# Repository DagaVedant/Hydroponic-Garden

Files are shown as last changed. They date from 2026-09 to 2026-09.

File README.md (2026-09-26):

# Vertical Hydroponic Garden
a fully MODULAR, 3D PRINTED hydroponic tower which needs NO EXTRA tubing because its designed to distribute the water evenly


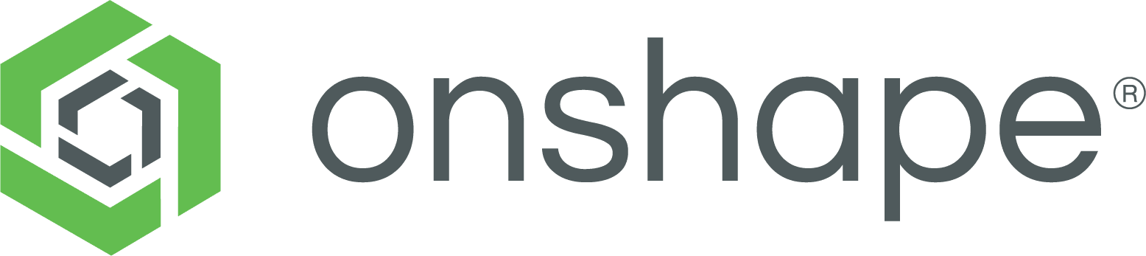
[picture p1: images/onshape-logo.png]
View on Onshape
[](https://cad.onshape.com/documents/e7b652182e17b56d968bf971/w/74d572342f8ebf967bd0880e/e/9edb8eefc30c47e9fd32fa36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)

## why

i wanted a hydroponic tower thats one efficent, two scalable, and doesnt need tons of tubes to water each layer and this design only needs one pump, its modular, and each level gets the same amount of water

## photos

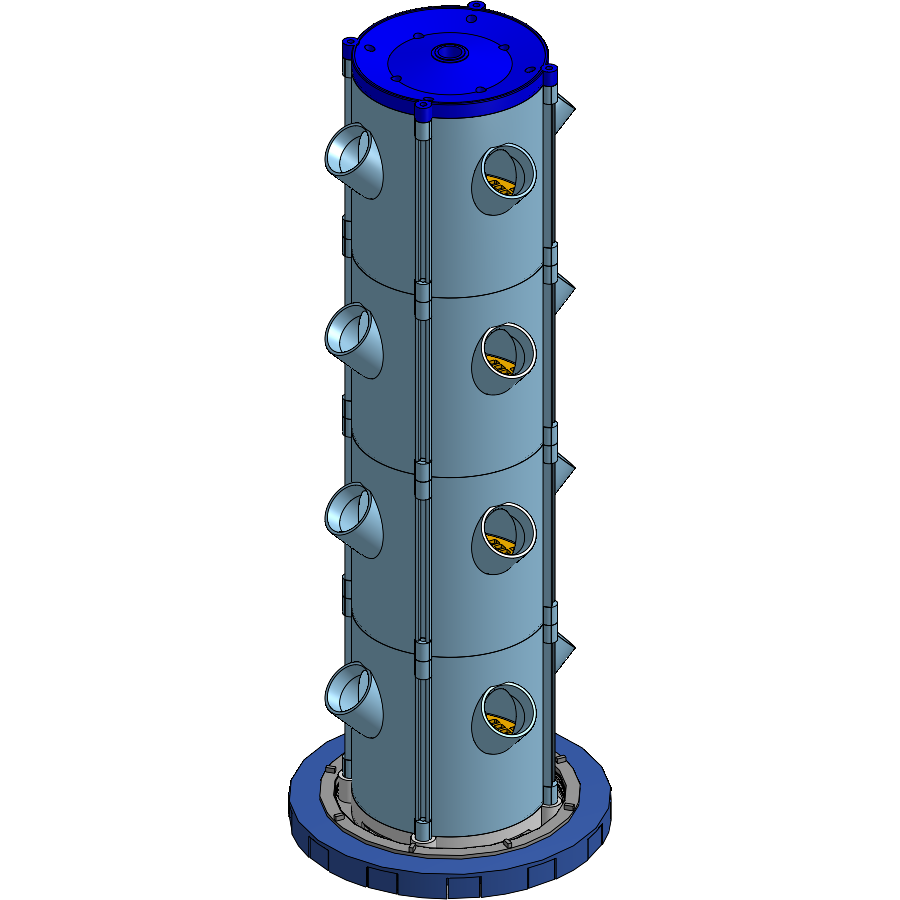
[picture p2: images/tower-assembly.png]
full tower assembly


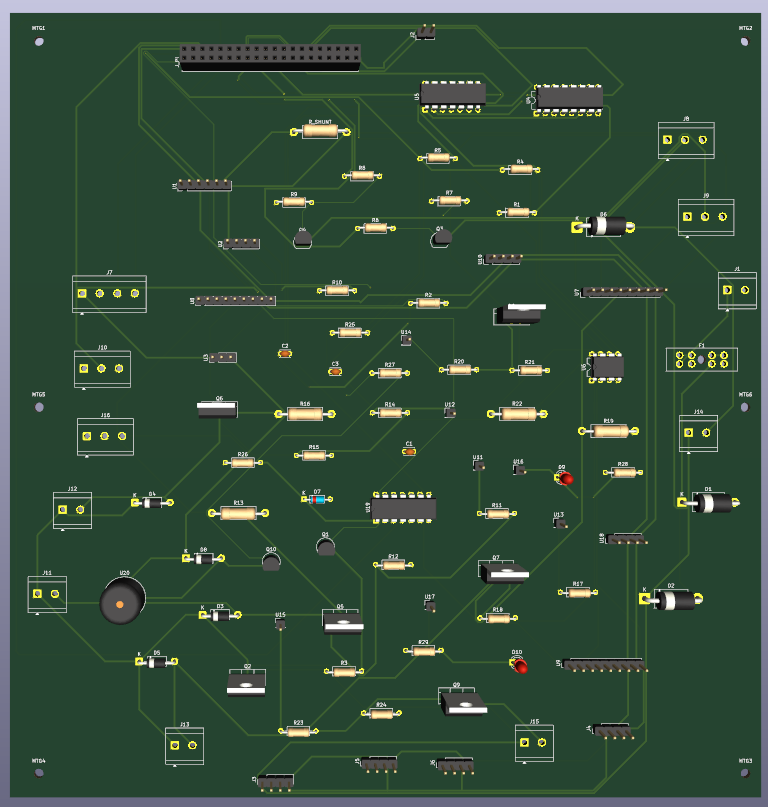
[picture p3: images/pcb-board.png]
pcb


the hat is a single 4-layer board, 217 x 226mm (down from an original 330 x 283mm)

## non-pcb wiring

```
120 V AC wall
  └── GFCI outlet, manual reset
        ├── pump, 30 W
        ├── 12 V 100 W PSU
        │     ├── LED strip, fan
        │     └── 3 dosing pumps
        └── Pi 5, over its own USB-C
```

## repo

| | |
|---|---|
| [BOM.csv](BOM.csv) | Bill Of Materials [below](#bill-of-materials) |
| [CAD/](CAD/) | .STEP export + what each file is on the onshape |
| [PCB/](PCB/) | raspberry pi 5 hat (`.kicad_pro`/`.kicad_sch`/`.kicad_pcb`)|
| [pi/](pi/) | the pi firmware `control.py`, `store.py`, `web.py` |
| [twoboard_vertical_garden/](twoboard_vertical_garden/) | archived design which saved like 50 bucks|

## bill of materials

just copied from [BOM.csv](BOM.csv)

| Item | Description | Qty | Unit Price (USD) | Total (USD) | Supplier | Status |
|---|---|---|---|---|---|---|
| **ALREADY OWN** |  |  |  |  |  |  |
| 5 gal bucket | 302mm OD, 368mm tall | 1 | 0.00 | 0.00 | N/A | OWNED |
| GROWNEER SML-630 submersible pump | 550 GPH, 30W, 120V AC | 1 | 0.00 | 0.00 | N/A | OWNED |
| 1/2in PVC Schedule 40 pipe 10ft | 21.34mm OD | 1 | 0.00 | 0.00 | N/A | OWNED |
| Analog pH interface board | signal conditioning, BNC socket | 1 | 0.00 | 0.00 | Amazon | OWNED |
| | **SUBTOTAL** | | | **0.00** | | |
| **SELF FUNDED** |  |  |  |  |  |  |
| [PETG filament white 1kg](https://www.amazon.com/ELEGOO-Filament-Dimensional-Accuracy-Printers/dp/B0D41YYVJN) | Elegoo, 1.75mm, 2 spools | 2 | 15.99 | 31.98 | Amazon | SELF-FUNDED |
| [PLA filament light blue 1kg](https://www.amazon.com/ELEGOO-Filament-Dimensional-Accuracy-Cardboard/dp/B0C6QD6456) | Elegoo sky blue, 1.75mm | 2 | 17.09 | 34.18 | Amazon | SELF-FUNDED |
| | **SUBTOTAL** | | | **66.16** | | |
| **PARTS I STILL NEED** |  |  |  |  |  |  |
| [Raspberry Pi 5](https://www.amazon.com/Raspberry-Pi-8GB-SC1112-Quad-core/dp/B0CK2FCG1K) | separate Pi, own power | 1 | 65.00 | 65.00 | N/A | TO BUY |
| [2in slotted mesh net pots (60-pack)](https://www.walmart.com/ip/60-Pack-2-Inch-Net-Cups-Slotted-Mesh-Wide-Lip-Filter-Plant-Net-Pot-Bucket-Basket-for-Hydroponics/917097535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) | 60-pack, 55mm lip | 1 | 10.97 | 10.97 | Walmart | TO BUY |
| [1/2in PVC MPT x Slip adapter](https://www.homedepot.com/p/LASCO-Fittings-1-2-in-PVC-Schedule-40-Male-MPT-x-Slip-Adapter-436005BC/317654558) | threaded to slip | 1 | 0.84 | 0.84 | Home Depot | TO BUY |
| [PVC bypass tee / ball valve / fittings](https://www.homedepot.com/p/Everbilt-1-2-in-PVC-Sch-40-Solvent-x-Solvent-Ball-Valve-107-633EB/319340955) | Everbilt 1/2in slip ball valve | 1 | 2.98 | 2.98 | Home Depot | TO BUY |
| [1/2in PVC slip tee](https://www.homedepot.com/p/Charlotte-Pipe-1-2-in-PVC-Schedule-40-S-x-S-x-S-Tee-PVC024000600HD/203812195) | Charlotte Pipe sch40, slip x3 | 1 | 0.87 | 0.87 | Home Depot | TO BUY |
| [1/2in PVC 90 elbow](https://www.homedepot.com/p/Charlotte-Pipe-1-2-in-PVC-Schedule-40-90-Degree-S-x-S-Elbow-Fitting-PVC023000600HD/203812033) | Charlotte Pipe sch40 slip | 1 | 0.78 | 0.78 | Home Depot | TO BUY |
| [PVC primer and cement](https://www.homedepot.com/p/Oatey-8-oz-Purple-CPVC-and-PVC-Primer-and-Regular-Clear-PVC-Cement-Combo-Pack-302483/100151579) | Oatey 8oz combo | 1 | 11.98 | 11.98 | Home Depot | TO BUY |
| [JSN-SR04T ultrasonic sensor](https://www.aliexpress.com/w/wholesale-jsn-sr04t-waterproof-ultrasonic-sensor.html) | non-contact level, 2-pack | 1 | 3.64 | 3.64 | AliExpress | TO BUY |
| [DS18B20 waterproof probe](https://www.amazon.com/DROK-Waterproof-Temperature-Resistors-Raspberry/dp/B0FLDTKW78) | water temp probe, 2-pack | 1 | 6.99 | 6.99 | Amazon | TO BUY |
| [SHT31 temp and humidity module](https://www.aliexpress.com/w/wholesale-sht31-temperature-humidity-module.html) | i2c 0x44, 2-pack | 1 | 3.50 | 3.50 | AliExpress | TO BUY |
| [SCD40 CO2 module](https://www.amazon.com/PAMEENCOS-Detects-Temperature-Humidity-Communication/dp/B0D9WLFWKS) | i2c CO2/temp/RH sensor | 1 | 21.99 | 21.99 | Amazon | TO BUY |
| [VEML7700 light sensor module](https://www.aliexpress.com/w/wholesale-veml7700.html) | i2c ambient light sensor | 1 | 4.70 | 4.70 | AliExpress | TO BUY |
| [12V white LED strip 5m](https://www.amazon.com/XUNATA-SMD5630-Dimmable-Linkable-Flexible/dp/B076HJFR58) | 5630 120led/m, neutral white | 1 | 17.99 | 17.99 | Amazon | TO BUY |
| [Aluminium LED channel + diffuser](https://www.amazon.com/Muzata-Aluminum-Mounting-Installations-Diffuser/dp/B01M09PBYX) | Muzata 17x7mm, 6x1m | 1 | 19.99 | 19.99 | Amazon | TO BUY |
| [12V 100W PSU](https://www.amazon.com/FSJEE-LED-Transformer/dp/B0GSVGLT2N) | IP67, 12V 8.3A, UL listed | 1 | 34.99 | 34.99 | Amazon | TO BUY |
| [Waterproof connectors and wire](https://www.aliexpress.com/w/wholesale-waterproof-connectors-automotive.html) | 26 set, 1-4 pin | 1 | 8.00 | 8.00 | AliExpress | TO BUY |
| [Wire crimping tool](https://www.amazon.com/Crimping-Amliber-Connectors-Electrical-Terminals/dp/B0D1FR76Q7) | ratcheting, 24-14 awg | 1 | 14.99 | 14.99 | Amazon | TO BUY |
| [22awg silicone hookup wire](https://www.amazon.com/Electric-Flexible-Silicone-different-Electronic/dp/B07G2JWYDW) | 6 colors, 8m each | 1 | 15.69 | 15.69 | Amazon | TO BUY |
| [16awg silicone wire 50ft](https://www.amazon.com/Silicone-Flexible-Stranded-Strands-MILAPEAK/dp/B07CMYVF3J) | 25ft red, 25ft black | 1 | 17.89 | 17.89 | Amazon | TO BUY |
| [Drip tray](https://www.amazon.com/Saucers-Extra-Deep-Drainage-Indoors-Plastic/dp/B0CPBC6ML3) | 16in saucer, 2-pack | 1 | 29.99 | 29.99 | Amazon | TO BUY |
| [Rockwool starter cubes 1.5in](https://www.amazon.com/dp/B0DJSXHQJ6) | 1.5in, 56-pack | 1 | 12.59 | 12.59 | Amazon | TO BUY |
| [pH replacement electrode](https://www.amazon.com/Connector-Electrode-Replacement-Aquarium-Hydroponics/dp/B07KG7RVVH) | BNC, 300cm cable | 1 | 17.90 | 17.90 | Amazon | TO BUY |
| [General Hydroponics pH Control Kit](https://www.amazon.com/dp/B000BNKWZY) | pH up/down plus indicator | 1 | 18.89 | 18.89 | Amazon | TO BUY |
| [General Hydroponics Flora Series trio](https://www.amazon.com/Hydroponics-GH-Flora-FloraMicro-FloraBloom/dp/B01HG98GX0) | micro/grow/bloom, 32oz quarts | 1 | 39.86 | 39.86 | Amazon | TO BUY |
| [Analog EC/TDS probe + interface board](https://www.amazon.com/Gravity-Waterproof-Anti-Polarization-0-1000ppm-Hydroponics/dp/B086GX2539) | DFRobot gravity kit, 0-1000ppm | 1 | 11.90 | 11.90 | Amazon | TO BUY |
| [pH and EC calibration solution set](https://www.amazon.com/GIDIGI-Calibration-Calibrating-Multifunction-Hydroponics/dp/B0GD6LMBLB) | 4x50ml, pH 4/7/10 + 1413 | 1 | 12.99 | 12.99 | Amazon | TO BUY |
| [pH probe storage solution](https://www.amazon.com/Biopharm-Electrode-Storage-Solution-Suitable/dp/B074G37V12) | Biopharm 250ml, KCl | 1 | 14.50 | 14.50 | Amazon | TO BUY |
| [ADS1115 16-bit I2C ADC](https://www.aliexpress.com/w/wholesale-16-bit-i2c-ads1115-adc-module.html) | 3-pack, all 3 used | 1 | 2.50 | 2.50 | AliExpress | TO BUY |
| [INA226 breakout module](https://www.aliexpress.com/w/wholesale-ina226.html) | i2c, strapped to 0x41 | 1 | 6.00 | 6.00 | AliExpress | TO BUY |
| [12V peristaltic dosing pump](https://www.amazon.com/INTLLAB-Peristaltic-Liquid-Aquarium-Analytical/dp/B07Q1C3PW2) | 5-100mL/min, 4-pack | 1 | 29.99 | 29.99 | Amazon | TO BUY |
| [Peristaltic pump tubing 10m](https://www.amazon.com/dp/B0DSQLWKFF/) | 3mm ID x 5mm OD | 1 | 9.39 | 9.39 | Amazon | TO BUY |
| [1L HDPE bottles with caps](https://www.amazon.com/United-Scientific-Supplies-33410-Capacity/dp/B07B32GNQ6) | wide mouth, 6-pack | 1 | 22.43 | 22.43 | Amazon | TO BUY |
| [PCB fabrication](https://cart.jlcpcb.com) | JLCPCB, 4-layer, no SMD | 1 | 74.37 | 74.37 | JLCPCB | TO BUY |
| [SB5H100 schottky diode](https://www.digikey.com/en/products/detail/vishay-general-semiconductor-diodes-division/SB5H100-E3-54/2146221) | DO-201AD, 5A/100V | 1 | 1.49 | 1.49 | Digikey | TO BUY |
| [1.5KE15A TVS diode](https://www.digikey.com/en/products/detail/stmicroelectronics/1-5KE15A/497-11371-1-ND/2674521) | DO-201AE axial | 1 | 1.10 | 1.10 | Digikey | TO BUY |
| [5 mOhm 1W axial shunt](https://www.digikey.com/en/products/filter/through-hole-resistors/1w/53) | DO0411, hand-solder | 1 | 2.20 | 2.20 | Digikey | TO BUY |
| [0.01 Ohm 1W axial shunt](https://www.amazon.com/10pcs-0R01%CE%A9J-Ceramic-Cement-Resistor/dp/B07PLSM9KZ) | LED strip current shunt | 1 | 14.49 | 14.49 | Amazon | TO BUY |
| [0.1 Ohm 1W axial shunt](https://www.amazon.com/CHANZON-J0010-RESISTOR-1W/dp/B08X75XKBS) | DO0411, per dosing pump | 3 | 2.00 | 6.00 | Amazon | TO BUY |
| [Buck converter module 12V to 5V](https://www.aliexpress.com/w/wholesale-mp1584.html) | MP1584/LM2596 style, few amps | 1 | 8.30 | 8.30 | AliExpress | TO BUY |
| [AMS1117 3.3V module](https://www.amazon.com/DollaTek-AMS1117-3-3-Voltage-Regulator-4-75V-12V/dp/B07PQPGMZ2) | breakout board, not SOT-223 | 1 | 6.99 | 6.99 | Amazon | TO BUY |
| [BS250 p-fet](https://www.digikey.com/en/products/detail/diodes-incorporated/BS250P/92630) | TO-92, high-side switch | 2 | 1.75 | 3.50 | Digikey | TO BUY |
| [IRLZ44N n-fet](https://www.digikey.com/en/products/detail/infineon-technologies/IRLZ44NPBF/811808) | TO-220, logic-level | 5 | 1.52 | 7.60 | Digikey | TO BUY |
| [2N7000 n-fet](https://www.digikey.com/en/products/detail/onsemi/2N7000G/1475375) | TO-92, gate driver | 2 | 0.65 | 1.30 | Digikey | TO BUY |
| [IRF9540N p-fet](https://www.digikey.com/en/products/detail/infineon-technologies/IRF9540NPBF/812088) | TO-220, interlock switch | 1 | 2.10 | 2.10 | Digikey | TO BUY |
| [DS3231 RTC breakout module](https://www.aliexpress.com/w/wholesale-ds3231-rtc-module.html) | i2c, own battery holder | 1 | 2.50 | 2.50 | AliExpress | TO BUY |
| [1N4148 diode](https://www.digikey.com/en/products/detail/onsemi/1N4148/458603) | DO-35, flow sensor clamp | 1 | 0.10 | 0.10 | Digikey | TO BUY |
| [CD4538BE dual monostable](https://www.digikey.com/en/products/detail/on-semiconductor/CD4538BCN/148229) | DIP-16, watchdog timer | 1 | 0.70 | 0.70 | Digikey | TO BUY |
| [CD4081BE quad AND gate](https://www.digikey.com/en/products/detail/CD4081BE/296-2066-5-ND/67323) | DIP-14, interlock gate | 1 | 1.11 | 1.11 | Digikey | TO BUY |
| [DIP IC socket assortment kit](https://www.aliexpress.com/w/wholesale-socket-dip.html) | 122pcs, 2.54mm pitch | 1 | 5.00 | 5.00 | AliExpress | TO BUY |
| [1N5819 schottky diode](https://www.digikey.com/en/products/detail/stmicroelectronics/1N5819/1037326) | DO-41, pump flyback | 3 | 0.35 | 1.05 | Digikey | TO BUY |
| [1N5822 schottky diode](https://www.digikey.com/en/products/detail/stmicroelectronics/1N5822/1037332) | DO-201AD, LED flyback | 1 | 0.50 | 0.50 | Digikey | TO BUY |
| [Littelfuse 178.6165.0001 blade fuse holder](https://www.digikey.com/en/products/detail/littelfuse-inc/178-6165-0001/2515815) | ATO holder, 12V input | 1 | 5.75 | 5.75 | Digikey | TO BUY |
| [ATO blade fuse 10A](https://www.digikey.com/en/products/detail/littelfuse-inc/0287010-L/3672098) | 12V input fuse | 1 | 7.99 | 7.99 | Amazon | TO BUY |
| [CUI TB007-508-02 terminal block](https://www.digikey.com/en/products/detail/cui-devices/TB007-508-02BE/10064127) | 5.08mm 2-pin | 6 | 0.72 | 4.32 | Digikey | TO BUY |
| [CUI TB007-508-03 terminal block](https://www.digikey.com/en/products/detail/cui-devices/TB007-508-03BE/10064128) | 5.08mm 3-pin | 2 | 0.95 | 1.90 | Digikey | TO BUY |
| [CUI TB007-508-04 terminal block](https://www.digikey.com/en/products/detail/cui-devices/TB007-508-04BE/10064129) | 5.08mm 4-pin | 1 | 1.15 | 1.15 | Digikey | TO BUY |
| [Gravity analog probe terminal block](https://www.digikey.com/en/products/detail/cui-devices/TB007-508-03BE/10064128) | 5.08mm 3-pin | 2 | 0.95 | 1.90 | Digikey | TO BUY |
| [2x20 stacking header for the pi 5](https://www.amazon.com/ELEDIY-20-40-Stacking-Header-Raspberry/dp/B071XCHZNB) | extra tall, clears cooler | 1 | 6.99 | 6.99 | Amazon | TO BUY |
| [2.54mm breakaway pin header strips](https://www.amazon.com/Gikfun-2-54mm-Single-Breakaway-Arduino/dp/B00U8OCENY) | 2.54mm, cut from strips | 2 | 3.00 | 6.00 | Amazon | TO BUY |
| [PCA9685 16-channel PWM breakout module](https://www.aliexpress.com/w/wholesale-pca9685.html) | i2c, strapped to 0x41 | 1 | 3.50 | 3.50 | AliExpress | TO BUY |
| [3mm THT LED assorted](https://www.amazon.com/250pcs-colors-Emitting-Diffused-Assorted/dp/B00XT0P1VQ) | status LEDs, assorted colors | 2 | 5.00 | 10.00 | Amazon | TO BUY |
| [Ceramic capacitor assortment kit](https://www.aliexpress.com/w/wholesale-ceramic-capacitor-kit-assorted.html) | 24 values, 480pcs | 1 | 5.00 | 5.00 | AliExpress | TO BUY |
| [Electrolytic capacitor assortment kit](https://www.aliexpress.com/w/wholesale-electrolytic-capacitors-kit.html) | 24 values, 500pcs | 1 | 7.00 | 7.00 | AliExpress | TO BUY |
| [Axial resistor kit 1% THT](https://www.aliexpress.com/item/32636020144.html) | 30 values, 600pcs | 1 | 3.57 | 3.57 | AliExpress | TO BUY |
| [#10-24 threaded rod 3ft](https://www.homedepot.com/p/Everbilt-10-24-x-3-ft-Zinc-Plated-Steel-Coarse-Threaded-Rod-2300/332733255) | UNC, one per corner | 4 | 2.98 | 11.92 | Home Depot | TO BUY |
| [#10-24 nyloc nuts](https://www.homedepot.com/p/Everbilt-10-24-Stainless-Steel-Nylon-Lock-Nut-4-Pieces-826011/317478988) | stainless, vibration-resistant | 2 | 1.57 | 3.14 | Home Depot | TO BUY |
| [M5 fender washers](https://www.homedepot.com/p/Hillman-Metric-Stainless-Fender-Washer-M5-44995/204786155) | stainless, 12-pack | 1 | 5.25 | 5.25 | Home Depot | TO BUY |
| **TOTAL COST** | sum of TO BUY items | | | **718.49** | | **TO BUY** |

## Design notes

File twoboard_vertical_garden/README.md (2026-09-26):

# twoboard_vertical_garden

the archived old pcb design for the vertical garden

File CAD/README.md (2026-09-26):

# cad

| # | name | file | volume |
|---|---|---|---|
| 00 | 50.6 test socket | `50.6 Test Socket.step` | |
| 01 | grow module | `Grow Module.step` | 656.61 cm3 |
| 02 | root grate | `Root Grate.step` | 50.51 cm3 |
| 03 | water spreader | `Water Spreader.step` | 36.72 cm3 |
| 04 | tower lid | `Tower Lid.step` | 247.22 cm3 |
| 05 | lid cap | `Lid Cap.step` | 80.57 cm3 |
| 06 | drain base | `Drain Base.step` | 118.80 cm3 |
| 07 | tank lid plate | `Tank Lid Plate.step` | 242.81 cm3 |
| 08 | tank ring | `Tank Ring.step` | 268.60 cm3 |

one tower is 4 modules, 4 grates, 4 spreaders, and one of the other stuff

## assembly

tower assembly

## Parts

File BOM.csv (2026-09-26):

Item | Description | Qty | Unit Price USD | Total USD | Item link | Supplier | Status
ALREADY OWN | no cost
5 gal bucket | 302mm OD, 368mm tall | 1 | 0.00 | 0.00 | N/A | N/A | OWNED
GROWNEER SML-630 submersible pump | 550 GPH, 30W, 120V AC | 1 | 0.00 | 0.00 | N/A | N/A | OWNED
1/2in PVC Schedule 40 pipe 10ft | 21.34mm OD | 1 | 0.00 | 0.00 | N/A | N/A | OWNED
Analog pH interface board | signal conditioning, BNC socket | 1 | 0.00 | 0.00 | N/A | Amazon | OWNED
 | SUBTOTAL |  |  | 0.00
SELF FUNDED | not part of funding ask
PETG filament white 1kg | Elegoo, 1.75mm, 2 spools | 2 | 15.99 | 31.98 | https://www.amazon.com/ELEGOO-Filament-Dimensional-Accuracy-Printers/dp/B0D41YYVJN | Amazon | SELF-FUNDED
PLA filament light blue 1kg | Elegoo sky blue, 1.75mm | 2 | 17.09 | 34.18 | https://www.amazon.com/ELEGOO-Filament-Dimensional-Accuracy-Cardboard/dp/B0C6QD6456 | Amazon | SELF-FUNDED
 | SUBTOTAL |  |  | 66.16
PARTS I STILL NEED | the funding request
Raspberry Pi 5 | separate Pi, own power | 1 | 65.00 | 65.00 | https://www.amazon.com/Raspberry-Pi-8GB-SC1112-Quad-core/dp/B0CK2FCG1K | N/A | TO BUY
2in slotted mesh net pots (60-pack) | 60-pack, 55mm lip | 1 | 10.97 | 10.97 | https://www.walmart.com/ip/60-Pack-2-Inch-Net-Cups-Slotted-Mesh-Wide-Lip-Filter-Plant-Net-Pot-Bucket-Basket-for-Hydroponics/917097535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 | Walmart | TO BUY
1/2in PVC MPT x Slip adapter | threaded to slip | 1 | 0.84 | 0.84 | https://www.homedepot.com/p/LASCO-Fittings-1-2-in-PVC-Schedule-40-Male-MPT-x-Slip-Adapter-436005BC/317654558 | Home Depot | TO BUY
PVC bypass tee / ball valve / fittings | Everbilt 1/2in slip ball valve | 1 | 2.98 | 2.98 | https://www.homedepot.com/p/Everbilt-1-2-in-PVC-Sch-40-Solvent-x-Solvent-Ball-Valve-107-633EB/319340955 | Home Depot | TO BUY
1/2in PVC slip tee | Charlotte Pipe sch40, slip x3 | 1 | 0.87 | 0.87 | https://www.homedepot.com/p/Charlotte-Pipe-1-2-in-PVC-Schedule-40-S-x-S-x-S-Tee-PVC024000600HD/203812195 | Home Depot | TO BUY
1/2in PVC 90 elbow | Charlotte Pipe sch40 slip | 1 | 0.78 | 0.78 | https://www.homedepot.com/p/Charlotte-Pipe-1-2-in-PVC-Schedule-40-90-Degree-S-x-S-Elbow-Fitting-PVC023000600HD/203812033 | Home Depot | TO BUY
PVC primer and cement | Oatey 8oz combo | 1 | 11.98 | 11.98 | https://www.homedepot.com/p/Oatey-8-oz-Purple-CPVC-and-PVC-Primer-and-Regular-Clear-PVC-Cement-Combo-Pack-302483/100151579 | Home Depot | TO BUY
JSN-SR04T ultrasonic sensor | non-contact level, 2-pack | 1 | 3.64 | 3.64 | https://www.aliexpress.com/w/wholesale-jsn-sr04t-waterproof-ultrasonic-sensor.html | AliExpress | TO BUY
DS18B20 waterproof probe | water temp probe, 2-pack | 1 | 6.99 | 6.99 | https://www.amazon.com/DROK-Waterproof-Temperature-Resistors-Raspberry/dp/B0FLDTKW78 | Amazon | TO BUY
SHT31 temp and humidity module | i2c 0x44, 2-pack | 1 | 3.50 | 3.50 | https://www.aliexpress.com/w/wholesale-sht31-temperature-humidity-module.html | AliExpress | TO BUY
SCD40 CO2 module | i2c CO2/temp/RH sensor | 1 | 21.99 | 21.99 | https://www.amazon.com/PAMEENCOS-Detects-Temperature-Humidity-Communication/dp/B0D9WLFWKS | Amazon | TO BUY
VEML7700 light sensor module | i2c ambient light sensor | 1 | 4.70 | 4.70 | https://www.aliexpress.com/w/wholesale-veml7700.html | AliExpress | TO BUY
12V white LED strip 5m | 5630 120led/m, neutral white | 1 | 17.99 | 17.99 | https://www.amazon.com/XUNATA-SMD5630-Dimmable-Linkable-Flexible/dp/B076HJFR58 | Amazon | TO BUY
Aluminium LED channel + diffuser | Muzata 17x7mm, 6x1m | 1 | 19.99 | 19.99 | https://www.amazon.com/Muzata-Aluminum-Mounting-Installations-Diffuser/dp/B01M09PBYX | Amazon | TO BUY
12V 100W PSU | IP67, 12V 8.3A, UL listed | 1 | 34.99 | 34.99 | https://www.amazon.com/FSJEE-LED-Transformer/dp/B0GSVGLT2N | Amazon | TO BUY
Waterproof connectors and wire | 26 set, 1-4 pin | 1 | 8.00 | 8.00 | https://www.aliexpress.com/w/wholesale-waterproof-connectors-automotive.html | AliExpress | TO BUY
Wire crimping tool | ratcheting, 24-14 awg | 1 | 14.99 | 14.99 | https://www.amazon.com/Crimping-Amliber-Connectors-Electrical-Terminals/dp/B0D1FR76Q7 | Amazon | TO BUY
22awg silicone hookup wire | 6 colors, 8m each | 1 | 15.69 | 15.69 | https://www.amazon.com/Electric-Flexible-Silicone-different-Electronic/dp/B07G2JWYDW | Amazon | TO BUY
16awg silicone wire 50ft | 25ft red, 25ft black | 1 | 17.89 | 17.89 | https://www.amazon.com/Silicone-Flexible-Stranded-Strands-MILAPEAK/dp/B07CMYVF3J | Amazon | TO BUY
Drip tray | 16in saucer, 2-pack | 1 | 29.99 | 29.99 | https://www.amazon.com/Saucers-Extra-Deep-Drainage-Indoors-Plastic/dp/B0CPBC6ML3 | Amazon | TO BUY
Rockwool starter cubes 1.5in | 1.5in, 56-pack | 1 | 12.59 | 12.59 | https://www.amazon.com/dp/B0DJSXHQJ6 | Amazon | TO BUY
pH replacement electrode | BNC, 300cm cable | 1 | 17.90 | 17.90 | https://www.amazon.com/Connector-Electrode-Replacement-Aquarium-Hydroponics/dp/B07KG7RVVH | Amazon | TO BUY
General Hydroponics pH Control Kit | pH up/down plus indicator | 1 | 18.89 | 18.89 | https://www.amazon.com/dp/B000BNKWZY | Amazon | TO BUY
General Hydroponics Flora Series trio | micro/grow/bloom, 32oz quarts | 1 | 39.86 | 39.86 | https://www.amazon.com/Hydroponics-GH-Flora-FloraMicro-FloraBloom/dp/B01HG98GX0 | Amazon | TO BUY
Analog EC/TDS probe + interface board | DFRobot gravity kit, 0-1000ppm | 1 | 11.90 | 11.90 | https://www.amazon.com/Gravity-Waterproof-Anti-Polarization-0-1000ppm-Hydroponics/dp/B086GX2539 | Amazon | TO BUY
pH and EC calibration solution set | 4x50ml, pH 4/7/10 + 1413 | 1 | 12.99 | 12.99 | https://www.amazon.com/GIDIGI-Calibration-Calibrating-Multifunction-Hydroponics/dp/B0GD6LMBLB | Amazon | TO BUY
pH probe storage solution | Biopharm 250ml, KCl | 1 | 14.50 | 14.50 | https://www.amazon.com/Biopharm-Electrode-Storage-Solution-Suitable/dp/B074G37V12 | Amazon | TO BUY
ADS1115 16-bit I2C ADC | 3-pack, all 3 used | 1 | 2.50 | 2.50 | https://www.aliexpress.com/w/wholesale-16-bit-i2c-ads1115-adc-module.html | AliExpress | TO BUY
INA226 breakout module | i2c, strapped to 0x41 | 1 | 6.00 | 6.00 | https://www.aliexpress.com/w/wholesale-ina226.html | AliExpress | TO BUY
12V peristaltic dosing pump | 5-100mL/min, 4-pack | 1 | 29.99 | 29.99 | https://www.amazon.com/INTLLAB-Peristaltic-Liquid-Aquarium-Analytical/dp/B07Q1C3PW2 | Amazon | TO BUY
Peristaltic pump tubing 10m | 3mm ID x 5mm OD | 1 | 9.39 | 9.39 | https://www.amazon.com/dp/B0DSQLWKFF/ | Amazon | TO BUY
1L HDPE bottles with caps | wide mouth, 6-pack | 1 | 22.43 | 22.43 | https://www.amazon.com/United-Scientific-Supplies-33410-Capacity/dp/B07B32GNQ6 | Amazon | TO BUY
PCB fabrication | JLCPCB, 4-layer, no SMD | 1 | 74.37 | 74.37 | https://cart.jlcpcb.com | JLCPCB | TO BUY
SB5H100 schottky diode | DO-201AD, 5A/100V | 1 | 1.49 | 1.49 | https://www.digikey.com/en/products/detail/vishay-general-semiconductor-diodes-division/SB5H100-E3-54/2146221 | Digikey | TO BUY
1.5KE15A TVS diode | DO-201AE axial | 1 | 1.10 | 1.10 | https://www.digikey.com/en/products/detail/stmicroelectronics/1-5KE15A/497-11371-1-ND/2674521 | Digikey | TO BUY
5 mOhm 1W axial shunt | DO0411, hand-solder | 1 | 2.20 | 2.20 | https://www.digikey.com/en/products/filter/through-hole-resistors/1w/53 | Digikey | TO BUY
0.01 Ohm 1W axial shunt | LED strip current shunt | 1 | 14.49 | 14.49 | https://www.amazon.com/10pcs-0R01%CE%A9J-Ceramic-Cement-Resistor/dp/B07PLSM9KZ | Amazon | TO BUY
0.1 Ohm 1W axial shunt | DO0411, per dosing pump | 3 | 2.00 | 6.00 | https://www.amazon.com/CHANZON-J0010-RESISTOR-1W/dp/B08X75XKBS | Amazon | TO BUY
Buck converter module 12V to 5V | MP1584/LM2596 style, few amps | 1 | 8.30 | 8.30 | https://www.aliexpress.com/w/wholesale-mp1584.html | AliExpress | TO BUY
AMS1117 3.3V module | breakout board, not SOT-223 | 1 | 6.99 | 6.99 | https://www.amazon.com/DollaTek-AMS1117-3-3-Voltage-Regulator-4-75V-12V/dp/B07PQPGMZ2 | Amazon | TO BUY
BS250 p-fet | TO-92, high-side switch | 2 | 1.75 | 3.50 | https://www.digikey.com/en/products/detail/diodes-incorporated/BS250P/92630 | Digikey | TO BUY
IRLZ44N n-fet | TO-220, logic-level | 5 | 1.52 | 7.60 | https://www.digikey.com/en/products/detail/infineon-technologies/IRLZ44NPBF/811808 | Digikey | TO BUY
2N7000 n-fet | TO-92, gate driver | 2 | 0.65 | 1.30 | https://www.digikey.com/en/products/detail/onsemi/2N7000G/1475375 | Digikey | TO BUY
IRF9540N p-fet | TO-220, interlock switch | 1 | 2.10 | 2.10 | https://www.digikey.com/en/products/detail/infineon-technologies/IRF9540NPBF/812088 | Digikey | TO BUY
DS3231 RTC breakout module | i2c, own battery holder | 1 | 2.50 | 2.50 | https://www.aliexpress.com/w/wholesale-ds3231-rtc-module.html | AliExpress | TO BUY
1N4148 diode | DO-35, flow sensor clamp | 1 | 0.10 | 0.10 | https://www.digikey.com/en/products/detail/onsemi/1N4148/458603 | Digikey | TO BUY
CD4538BE dual monostable | DIP-16, watchdog timer | 1 | 0.70 | 0.70 | https://www.digikey.com/en/products/detail/on-semiconductor/CD4538BCN/148229 | Digikey | TO BUY
CD4081BE quad AND gate | DIP-14, interlock gate | 1 | 1.11 | 1.11 | https://www.digikey.com/en/products/detail/CD4081BE/296-2066-5-ND/67323 | Digikey | TO BUY
DIP IC socket assortment kit | 122pcs, 2.54mm pitch | 1 | 5.00 | 5.00 | https://www.aliexpress.com/w/wholesale-socket-dip.html | AliExpress | TO BUY
1N5819 schottky diode | DO-41, pump flyback | 3 | 0.35 | 1.05 | https://www.digikey.com/en/products/detail/stmicroelectronics/1N5819/1037326 | Digikey | TO BUY
1N5822 schottky diode | DO-201AD, LED flyback | 1 | 0.50 | 0.50 | https://www.digikey.com/en/products/detail/stmicroelectronics/1N5822/1037332 | Digikey | TO BUY
Littelfuse 178.6165.0001 blade fuse holder | ATO holder, 12V input | 1 | 5.75 | 5.75 | https://www.digikey.com/en/products/detail/littelfuse-inc/178-6165-0001/2515815 | Digikey | TO BUY
ATO blade fuse 10A | 12V input fuse | 1 | 7.99 | 7.99 | https://www.digikey.com/en/products/detail/littelfuse-inc/0287010-L/3672098 | Amazon | TO BUY
CUI TB007-508-02 terminal block | 5.08mm 2-pin | 6 | 0.72 | 4.32 | https://www.digikey.com/en/products/detail/cui-devices/TB007-508-02BE/10064127 | Digikey | TO BUY
CUI TB007-508-03 terminal block | 5.08mm 3-pin | 2 | 0.95 | 1.90 | https://www.digikey.com/en/products/detail/cui-devices/TB007-508-03BE/10064128 | Digikey | TO BUY
CUI TB007-508-04 terminal block | 5.08mm 4-pin | 1 | 1.15 | 1.15 | https://www.digikey.com/en/products/detail/cui-devices/TB007-508-04BE/10064129 | Digikey | TO BUY
Gravity analog probe terminal block | 5.08mm 3-pin | 2 | 0.95 | 1.90 | https://www.digikey.com/en/products/detail/cui-devices/TB007-508-03BE/10064128 | Digikey | TO BUY
2x20 stacking header for the pi 5 | extra tall, clears cooler | 1 | 6.99 | 6.99 | https://www.amazon.com/ELEDIY-20-40-Stacking-Header-Raspberry/dp/B071XCHZNB | Amazon | TO BUY
2.54mm breakaway pin header strips | 2.54mm, cut from strips | 2 | 3.00 | 6.00 | https://www.amazon.com/Gikfun-2-54mm-Single-Breakaway-Arduino/dp/B00U8OCENY | Amazon | TO BUY
PCA9685 16-channel PWM breakout module | i2c, strapped to 0x41 | 1 | 3.50 | 3.50 | https://www.aliexpress.com/w/wholesale-pca9685.html | AliExpress | TO BUY
3mm THT LED assorted | status LEDs, assorted colors | 2 | 5.00 | 10.00 | https://www.amazon.com/250pcs-colors-Emitting-Diffused-Assorted/dp/B00XT0P1VQ | Amazon | TO BUY
Ceramic capacitor assortment kit | 24 values, 480pcs | 1 | 5.00 | 5.00 | https://www.aliexpress.com/w/wholesale-ceramic-capacitor-kit-assorted.html | AliExpress | TO BUY
Electrolytic capacitor assortment kit | 24 values, 500pcs | 1 | 7.00 | 7.00 | https://www.aliexpress.com/w/wholesale-electrolytic-capacitors-kit.html | AliExpress | TO BUY
Axial resistor kit 1% THT | 30 values, 600pcs | 1 | 3.57 | 3.57 | https://www.aliexpress.com/item/32636020144.html | AliExpress | TO BUY
#10-24 threaded rod 3ft | UNC, one per corner | 4 | 2.98 | 11.92 | https://www.homedepot.com/p/Everbilt-10-24-x-3-ft-Zinc-Plated-Steel-Coarse-Threaded-Rod-2300/332733255 | Home Depot | TO BUY
#10-24 nyloc nuts | stainless, vibration-resistant | 2 | 1.57 | 3.14 | https://www.homedepot.com/p/Everbilt-10-24-Stainless-Steel-Nylon-Lock-Nut-4-Pieces-826011/317478988 | Home Depot | TO BUY
M5 fender washers | stainless, 12-pack | 1 | 5.25 | 5.25 | https://www.homedepot.com/p/Hillman-Metric-Stainless-Fender-Washer-M5-44995/204786155 | Home Depot | TO BUY
TOTAL COST | sum of TO BUY items |  |  | 718.49 |  |  | TO BUY

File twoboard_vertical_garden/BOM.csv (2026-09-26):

Item | Description | Qty | Unit Price USD | Total USD | Item link | Supplier | Status
ALREADY OWN | no cost
5 gal bucket | 302mm OD, 368mm tall | 1 | 0.00 | 0.00 | N/A | N/A | OWNED
GROWNEER SML-630 submersible pump | 550 GPH, 30W, 120V AC | 1 | 0.00 | 0.00 | N/A | N/A | OWNED
1/2in PVC Schedule 40 pipe 10ft | 21.34mm OD | 1 | 0.00 | 0.00 | N/A | N/A | OWNED
Raspberry Pi 4B | runs broker, control, dashboard | 1 | 0.00 | 0.00 | N/A | N/A | OWNED
Analog pH interface board | signal conditioning, BNC socket | 1 | 0.00 | 0.00 | N/A | Amazon | OWNED
 | SUBTOTAL |  |  | 0.00
SELF FUNDED | not part of funding ask
PLA and PETG filament | 2-3kg, PETG + PLA | 2 | 0.00 | 0.00 | N/A | N/A | SELF-FUNDED
 | SUBTOTAL |  |  | 0.00
PARTS I STILL NEED | the funding request
2in slotted mesh net pots (60-pack) | 60-pack, 55mm lip | 1 | 10.97 | 10.97 | https://www.walmart.com/ip/60-Pack-2-Inch-Net-Cups-Slotted-Mesh-Wide-Lip-Filter-Plant-Net-Pot-Bucket-Basket-for-Hydroponics/917097535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 | Walmart | TO BUY
1/2in PVC MPT x Slip adapter | threaded to slip | 1 | 0.84 | 0.84 | https://www.homedepot.com/p/LASCO-Fittings-1-2-in-PVC-Schedule-40-Male-MPT-x-Slip-Adapter-436005BC/317654558 | Home Depot | TO BUY
PVC bypass tee / ball valve / fittings | Everbilt 1/2in slip ball valve | 1 | 2.98 | 2.98 | https://www.homedepot.com/p/Everbilt-1-2-in-PVC-Sch-40-Solvent-x-Solvent-Ball-Valve-107-633EB/319340955 | Home Depot | TO BUY
1/2in PVC slip tee | Charlotte Pipe sch40, slip x3 | 1 | 0.87 | 0.87 | https://www.homedepot.com/p/Charlotte-Pipe-1-2-in-PVC-Schedule-40-S-x-S-x-S-Tee-PVC024000600HD/203812195 | Home Depot | TO BUY
1/2in PVC 90 elbow | Charlotte Pipe sch40 slip | 1 | 0.78 | 0.78 | https://www.homedepot.com/p/Charlotte-Pipe-1-2-in-PVC-Schedule-40-90-Degree-S-x-S-Elbow-Fitting-PVC023000600HD/203812033 | Home Depot | TO BUY
PVC primer and cement | Oatey 8oz combo | 1 | 11.98 | 11.98 | https://www.homedepot.com/p/Oatey-8-oz-Purple-CPVC-and-PVC-Primer-and-Regular-Clear-PVC-Cement-Combo-Pack-302483/100151579 | Home Depot | TO BUY
JSN-SR04T ultrasonic sensor | non-contact level, 2-pack | 1 | 9.49 | 9.49 | https://www.amazon.com/Integrated-Transducer-Ultrasonic-Waterproof-JSN-SR04T-V3-0/dp/B0CP5YQF43 | Amazon | TO BUY
DS18B20 waterproof probe | water temp probe, 2-pack | 1 | 6.99 | 6.99 | https://www.amazon.com/DROK-Waterproof-Temperature-Resistors-Raspberry/dp/B0FLDTKW78 | Amazon | TO BUY
SHT31 temp and humidity module | i2c 0x44, 2-pack | 1 | 9.99 | 9.99 | https://www.amazon.com/MTDELE-Temperature-Humidity-Compatible-Interface/dp/B0F9WVY98D | Amazon | TO BUY
12V white LED strip 5m | 5630 120led/m, neutral white | 1 | 17.99 | 17.99 | https://www.amazon.com/XUNATA-SMD5630-Dimmable-Linkable-Flexible/dp/B076HJFR58 | Amazon | TO BUY
Aluminium LED channel + diffuser | Muzata 17x7mm, 6x1m | 1 | 19.99 | 19.99 | https://www.amazon.com/Muzata-Aluminum-Mounting-Installations-Diffuser/dp/B01M09PBYX | Amazon | TO BUY
12V 100W PSU | IP67, 12V 8.3A, UL listed | 1 | 34.99 | 34.99 | https://www.amazon.com/FSJEE-LED-Transformer/dp/B0GSVGLT2N | Amazon | TO BUY
Waterproof connectors and wire | 50 set, 1-6 pin | 1 | 39.99 | 39.99 | https://www.amazon.com/Twippo-Waterproof-Automotive-Electrical-Connectors/dp/B0CBJV2WSM | Amazon | TO BUY
22awg silicone hookup wire | 6 colors, 8m each | 1 | 15.69 | 15.69 | https://www.amazon.com/Electric-Flexible-Silicone-different-Electronic/dp/B07G2JWYDW | Amazon | TO BUY
16awg silicone wire 50ft | 25ft red, 25ft black | 1 | 17.89 | 17.89 | https://www.amazon.com/Silicone-Flexible-Stranded-Strands-MILAPEAK/dp/B07CMYVF3J | Amazon | TO BUY
Drip tray | 16in saucer, 2-pack | 1 | 29.99 | 29.99 | https://www.amazon.com/Saucers-Extra-Deep-Drainage-Indoors-Plastic/dp/B0CPBC6ML3?th=1 | Amazon | TO BUY
Rockwool starter cubes 1.5in | 1.5in, 56-pack | 1 | 12.59 | 12.59 | https://www.amazon.com/dp/B0DJSXHQJ6/ref=twister_B0DJSZQ1ZC?_encoding=UTF8&th=1 | Amazon | TO BUY
pH replacement electrode | BNC, 300cm cable | 1 | 17.90 | 17.90 | https://www.amazon.com/Connector-Electrode-Replacement-Aquarium-Hydroponics/dp/B07KG7RVVH | Amazon | TO BUY
General Hydroponics pH Control Kit | pH up/down plus indicator | 1 | 18.89 | 18.89 | https://www.amazon.com/dp/B000BNKWZY | Amazon | TO BUY
General Hydroponics Flora Series trio | micro/grow/bloom, 32oz quarts | 1 | 39.86 | 39.86 | https://www.amazon.com/Hydroponics-GH-Flora-FloraMicro-FloraBloom/dp/B01HG98GX0 | Amazon | TO BUY
Analog EC/TDS probe + interface board | DFRobot gravity kit, 0-1000ppm | 1 | 11.90 | 11.90 | https://www.amazon.com/Gravity-Waterproof-Anti-Polarization-0-1000ppm-Hydroponics/dp/B086GX2539 | Amazon | TO BUY
pH and EC calibration solution set | 4x50ml, pH 4/7/10 + 1413 | 1 | 12.99 | 12.99 | https://www.amazon.com/GIDIGI-Calibration-Calibrating-Multifunction-Hydroponics/dp/B0GD6LMBLB | Amazon | TO BUY
pH probe storage solution | Biopharm 250ml, KCl | 1 | 14.50 | 14.50 | https://www.amazon.com/Biopharm-Electrode-Storage-Solution-Suitable/dp/B074G37V12 | Amazon | TO BUY
ADS1115 16-bit I2C ADC | 3-pack | 1 | 11.89 | 11.89 | https://www.amazon.com/HiLetgo-Converter-Programmable-Amplifier-Development/dp/B07VPFLSMX | Amazon | TO BUY
12V peristaltic dosing pump | 5-100mL/min, 4-pack | 1 | 29.99 | 29.99 | https://www.amazon.com/INTLLAB-Peristaltic-Liquid-Aquarium-Analytical/dp/B07Q1C3PW2 | Amazon | TO BUY
Peristaltic pump tubing 10m | 3mm ID x 5mm OD | 1 | 9.39 | 9.39 | https://www.amazon.com/dp/B0DSQLWKFF/ | Amazon | TO BUY
1L HDPE bottles with caps | wide mouth, 6-pack | 1 | 22.43 | 22.43 | https://www.amazon.com/United-Scientific-Supplies-33410-Capacity/dp/B07B32GNQ6 | Amazon | TO BUY
PCB fabrication | JLCPCB, hat + load board | 1 | 187.90 | 187.90 | https://cart.jlcpcb.com | JLCPCB | TO BUY
SB5H100 schottky diode | DO-201AD, 5A/100V | 3 | 1.49 | 4.47 | https://www.digikey.com/en/products/detail/vishay-general-semiconductor-diodes-division/SB5H100-E3-54/2146221 | Digikey | TO BUY
1.5KE15A TVS diode | DO-201AE axial | 2 | 1.10 | 2.20 | https://www.digikey.com/en/products/detail/stmicroelectronics/1-5KE15A/497-11371-1-ND/2674521 | Digikey | TO BUY
1.5KE6.5CA TVS diode | DO-201AE axial | 2 | 0.65 | 1.30 | https://www.digikey.com/en/products/detail/littelfuse-inc/1-5KE6-8CA/285844 | Digikey | TO BUY
INA226 breakout module | i2c voltage/current monitor | 1 | 6.50 | 6.50 | https://www.amazon.com/Monitoring-Interface-Bi-Directional-Zero-Drift-DC2-7-5-5/dp/B0HFHML7Q1 | Amazon | TO BUY
5 mOhm 1W axial shunt | DO0411, split shunt | 1 | 2.20 | 2.20 | https://www.digikey.com/en/products/filter/through-hole-resistors/1w/53 | Digikey | TO BUY
0.01 Ohm 1W axial shunt | DO0411, LED shunt | 1 | 2.20 | 2.20 | https://www.digikey.com/en/products/filter/through-hole-resistors/1w/53 | Digikey | TO BUY
0.1 Ohm 1W axial shunt | DO0411, per dosing pump | 3 | 1.95 | 5.85 | https://www.digikey.com/en/products/filter/through-hole-resistors/1w/53 | Digikey | TO BUY
Buck converter module 12V to 5V | MP1584/LM2596 style, hat + load | 2 | 5.00 | 10.00 | https://www.amazon.com/EBL-MP1584EN-Converter-Adjustable-Supply/dp/B08GSJVPB2 | Amazon | TO BUY
Li-ion charger breakout module (500mA) | 500mA, own status LED | 1 | 7.99 | 7.99 | https://www.amazon.com/HiLetgo-Lithium-Charging-Protection-Functions/dp/B07PKND8KG | Amazon | TO BUY
XL6009 boost breakout module | battery to 5V, UPS | 1 | 9.99 | 9.99 | https://www.amazon.com/HiLetgo-Adjustable-DC3-0-30V-DC5-35V-Converter/dp/B07BNHR4HW | Amazon | TO BUY
AMS1117 3.3V breakout module | breakout board, not SOT-223 | 1 | 6.99 | 6.99 | https://www.amazon.com/DollaTek-AMS1117-3-3-Voltage-Regulator-4-75V-12V/dp/B07PQPGMZ2 | Amazon | TO BUY
DS3231 RTC breakout module | i2c, own battery holder | 1 | 9.99 | 9.99 | https://www.amazon.com/HiLetgo-DS3231-DS3231SN-Module-PinHeader/dp/B0832PM954 | Amazon | TO BUY
Isolated RS485 breakout module | ADM2483-class isolated module | 1 | 12.99 | 12.99 | https://www.amazon.com/Module-Signal-Converter-Isolated-Industrial/dp/B07Z45HYW7 | Amazon | TO BUY
Current-sense amplifier breakout module | INA169-class, LED channel | 1 | 7.99 | 7.99 | https://www.amazon.com/NOYITO-INA169-High-Precision-Current-Breakout/dp/B07PMMX6MG | Amazon | TO BUY
IRLZ44N n-fet | TO-220, logic-level | 4 | 1.52 | 6.08 | https://www.digikey.com/en/products/detail/infineon-technologies/IRLZ44NPBF/811808 | Digikey | TO BUY
IRF9540N p-fet | TO-220, interlock switch | 1 | 2.10 | 2.10 | https://www.digikey.com/en/products/detail/infineon-technologies/IRF9540NPBF/812088 | Digikey | TO BUY
2N7000 n-fet | TO-92, gate driver | 8 | 0.65 | 5.20 | https://www.digikey.com/en/products/detail/onsemi/2N7000G/1475375 | Digikey | TO BUY
BS250 p-fet | TO-92, high-side switch | 2 | 1.75 | 3.50 | https://www.digikey.com/en/products/detail/diodes-incorporated/BS250P/92630 | Digikey | TO BUY
24LC32A/P eeprom | DIP-8, hat ID | 1 | 0.56 | 0.56 | https://www.digikey.com/en/products/detail/microchip-technology/24LC32A-P/249076 | Digikey | TO BUY
CD4538BE dual monostable | DIP-16, watchdog timer | 1 | 0.70 | 0.70 | https://www.digikey.com/en/products/detail/on-semiconductor/CD4538BCN/148229 | Digikey | TO BUY
CD4081BE quad AND gate | DIP-14, interlock gate | 1 | 1.11 | 1.11 | https://www.digikey.com/en/products/detail/CD4081BE/296-2066-5-ND/67323 | Digikey | TO BUY
CD40106BE hex schmitt inverter | DIP-14, flow pulse buffer | 1 | 0.77 | 0.77 | https://www.digikey.com/en/products/detail/texas-instruments/CD40106BE/376602 | Digikey | TO BUY
DIP-16 IC socket | one for CD4538 | 1 | 0.55 | 0.55 | https://www.digikey.com/en/products/detail/preci-dip/110-87-316-41-001101/1212-1009-ND/3757259 | Digikey | TO BUY
DIP-14 IC socket | two, CD4081/CD40106 | 2 | 0.50 | 1.00 | https://www.digikey.com/en/products/detail/on-shore-technology-inc/ED14DT/4147595 | Digikey | TO BUY
DIP-8 IC socket | one for EEPROM | 1 | 0.45 | 0.45 | https://www.digikey.com/en/products/detail/on-shore-technology-inc/ED08DT/4147594 | Digikey | TO BUY
1N5819 schottky diode | DO-41, pump/buzzer flyback | 6 | 0.35 | 2.10 | https://www.digikey.com/en/products/detail/stmicroelectronics/1N5819/1037326 | Digikey | TO BUY
1N4148 diode | DO-35, line clamps | 4 | 0.10 | 0.40 | https://www.digikey.com/en/products/detail/onsemi/1N4148/458603 | Digikey | TO BUY
Littelfuse 178.6165.0001 blade fuse holder | ATO holder, 12V | 2 | 5.75 | 11.50 | https://www.digikey.com/en/products/detail/littelfuse-inc/178-6165-0001/2515815 | Digikey | TO BUY
ATO blade fuses 10A and 7.5A | input + link fuses | 2 | 1.05 | 2.10 | https://www.digikey.com/en/products/detail/littelfuse-inc/0287010-L/3672098 | Amazon | TO BUY
THT cylindrical fuseholder (5x20mm) | Schurter-style, 5x20mm | 2 | 1.53 | 3.06 | https://www.digikey.com/en/products/detail/keystone-electronics/3550-2/2137310 | Digikey | TO BUY
5x20mm leaded fuse 3A | glass/ceramic, 5x20mm | 2 | 1.10 | 2.20 | https://www.digikey.com/en/products/detail/bel-fuse-inc/5TT-3-R/1009069 | Digikey | TO BUY
CUI TB007-508-02 terminal block | 5.08mm 2-pin | 6 | 0.72 | 4.32 | https://www.digikey.com/en/products/detail/cui-devices/TB007-508-02BE/10064127 | Digikey | TO BUY
CUI TB007-508-03 terminal block | 5.08mm 3-pin | 2 | 0.95 | 1.90 | https://www.digikey.com/en/products/detail/cui-devices/TB007-508-03BE/10064128 | Digikey | TO BUY
Gravity analog probe terminal block | 5.08mm 3-pin | 2 | 0.95 | 1.90 | https://www.digikey.com/en/products/detail/cui-devices/TB007-508-03BE/10064128 | Digikey | TO BUY
JST B3B-XH-A | XH 3-pin | 3 | 0.25 | 0.75 | https://www.digikey.com/en/products/detail/jst-sales-america-inc/B3B-XH-A-LF-SN/1651046 | Digikey | TO BUY
JST B4B-XH-A | XH 4-pin | 1 | 0.28 | 0.28 | https://www.digikey.com/en/products/detail/jst-sales-america-inc/B4B-XH-A/1651047 | Digikey | TO BUY
XH crimp housings and contacts | 3-pin x3, 4-pin x1 | 1 | 11.99 | 11.99 | https://www.amazon.com/GTIWUNG-480Pcs-JST-XH-Connector-Housing/dp/B07PRWF4BV | Amazon | TO BUY
2x20 stacking header for the pi | extra tall, clears pi | 1 | 6.99 | 6.99 | https://www.amazon.com/ELEDIY-20-40-Stacking-Header-Raspberry/dp/B071XCHZNB | Amazon | TO BUY
1x20 female header | two, pico socket | 2 | 3.50 | 7.00 | https://www.amazon.com/1x20P-20-Pin-2-54mm-Female-Header/dp/B00QL0G4TO | Amazon | TO BUY
2.54mm breakaway pin header strips | 2.54mm, cut from strips | 3 | 2.00 | 6.00 | https://www.amazon.com/Gikfun-2-54mm-Single-Breakaway-Arduino/dp/B00U8OCENY | Amazon | TO BUY
12mm active buzzer 5v | 5V, 7.6mm pitch | 1 | 6.99 | 6.99 | https://www.amazon.com/10PCS-Active-Buzzer-Magnetic-Buzzers/dp/B0D9SBJQYZ | Amazon | TO BUY
3mm THT LED assorted | status LEDs, assorted colors | 4 | 2.50 | 10.00 | https://www.amazon.com/250pcs-colors-Emitting-Diffused-Assorted/dp/B00XT0P1VQ | Amazon | TO BUY
Ceramic capacitor assortment kit | 24 values, 480pcs | 1 | 9.99 | 9.99 | https://www.amazon.com/Multilayer-Monolithic-Capacitor-Assortment-Electronics/dp/B0D2GVNDHY | Amazon | TO BUY
Electrolytic capacitor assortment kit | 24 values, 500pcs | 1 | 12.99 | 12.99 | https://www.amazon.com/OCR-Electrolytic-Capacitor-Assortment-0-1uF%EF%BC%8D1000uF/dp/B01MSQOX0Q | Amazon | TO BUY
Axial resistor kit 1% THT | many values, THT kit | 1 | 12.99 | 12.99 | https://www.amazon.com/Resistor-Assorted-Resistors-Assortment-Experiments/dp/B07L851T3V | Amazon | TO BUY
TOTAL COST | sum of TO BUY items |  |  | 849.78 |  |  | TO BUY

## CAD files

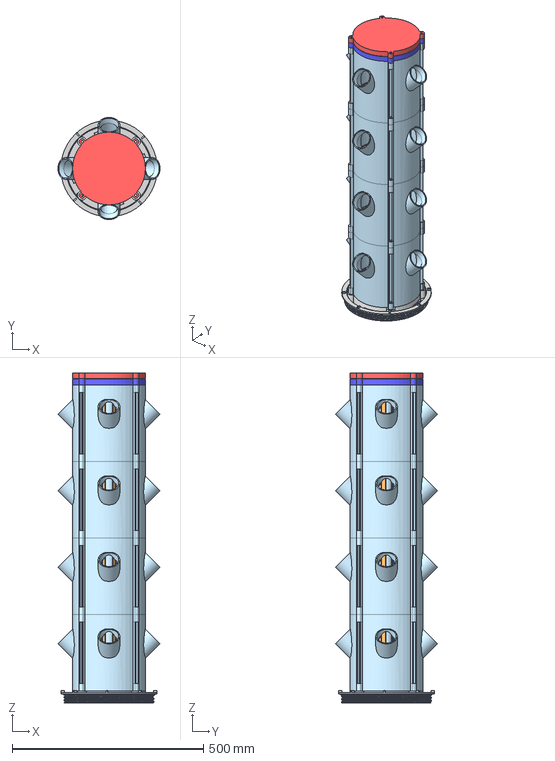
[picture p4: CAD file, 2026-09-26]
CAD/Tower Assembly.step
266.7 x 266.7 x 862.0 mm

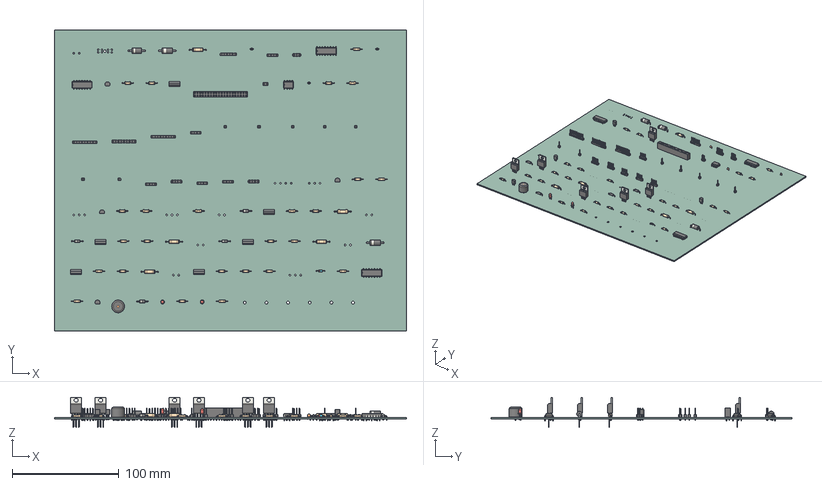
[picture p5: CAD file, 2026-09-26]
CAD/HAT.step
330.0 x 282.6 x 28.5 mm
PinHeader_1x04_P254mm_Vertical x 7
R_Axial_DIN0411_L99mm_D36mm_P1524mm_Horizontal x 5
R_Axial_DIN0207_L63mm_D25mm_P1016mm_Horizontal x 25
PinHeader_1x09_P254mm_Vertical x 3
C_Disc_D30mm_W20mm_P250mm x 3
PinHeader_1x01_P254mm_Vertical x 7
LED_D3.0mm x 2
DIP-8_W7.62mm
TO-92_Inline_Narrow x 4
D_DO-201AD_P15.24mm_Horizontal x 2
D_DO-201AE_P15.24mm_Horizontal
D_DO-35_SOD27_P7.62mm_Horizontal
PinSocket_2x20_P2.54mm_Vertical
D_DO-41_SOD81_P10.16mm_Horizontal x 4
PinHeader_1x02_P254mm_Vertical
TO-220-3_Vertical x 6
Buzzer_12x95RM76
PinHeader_1x03_P254mm_Vertical
DIP-16_W7.62mm
DIP-14_W7.62mm x 2
PinHeader_1x06_P254mm_Vertical
hat_PCB

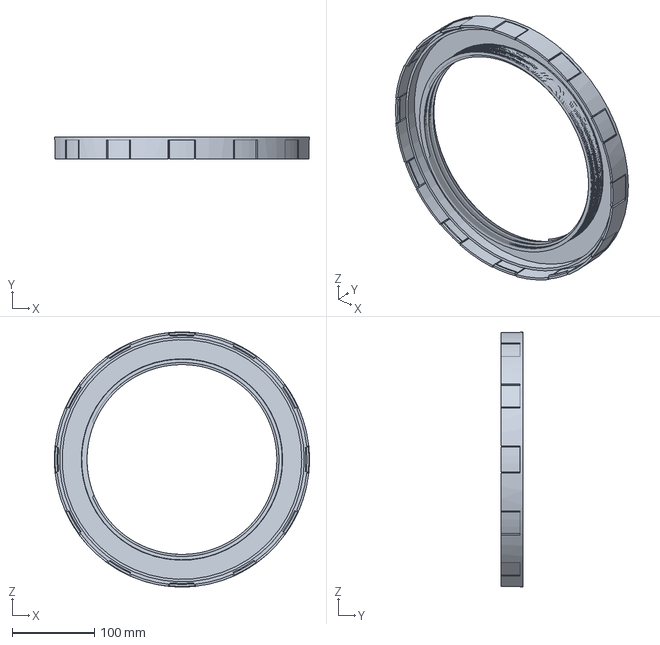
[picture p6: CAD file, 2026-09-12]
CAD/Tank Ring.step
310.7 x 27.2 x 310.7 mm

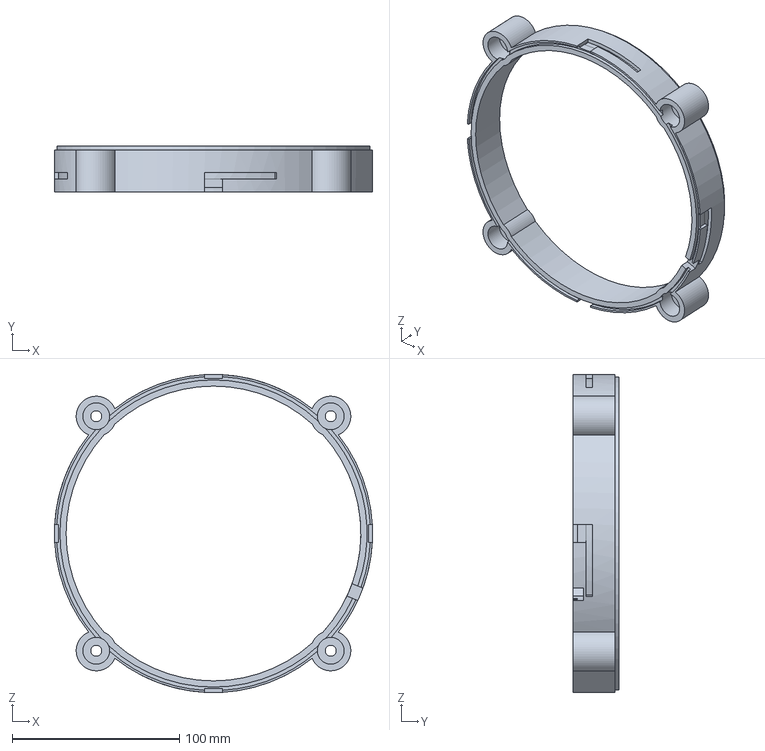
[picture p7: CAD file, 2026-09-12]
CAD/Drain Base.step
189.9 x 27.2 x 189.9 mm

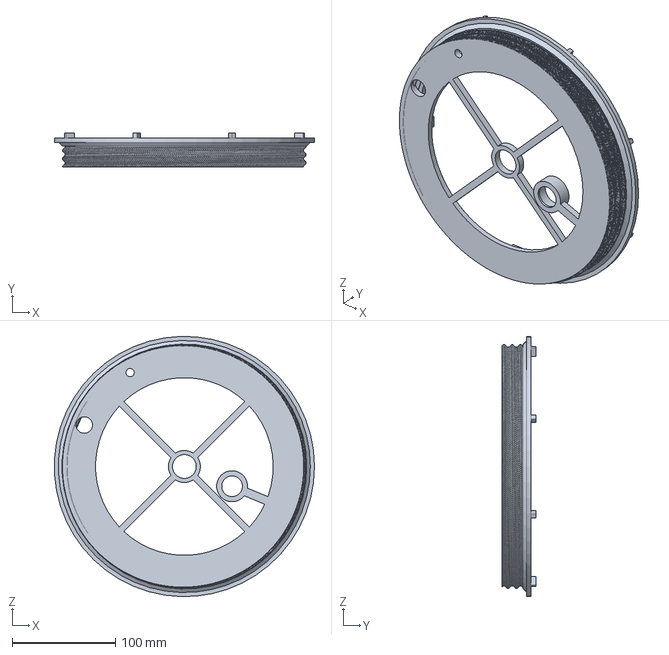
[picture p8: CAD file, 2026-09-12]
CAD/Tank Lid Plate.step
251.8 x 33.0 x 251.9 mm

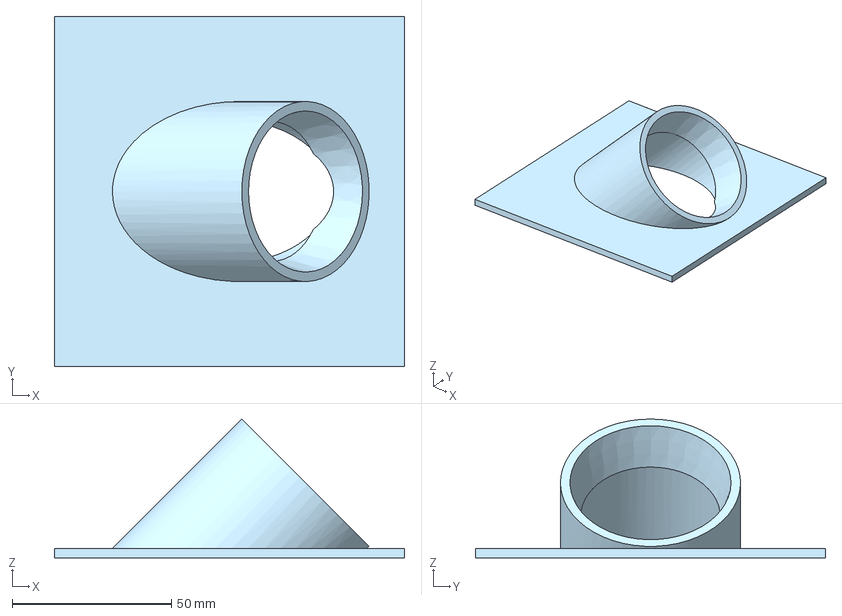
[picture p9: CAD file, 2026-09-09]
CAD/50.6 Test Socket.step
110.0 x 110.0 x 43.7 mm

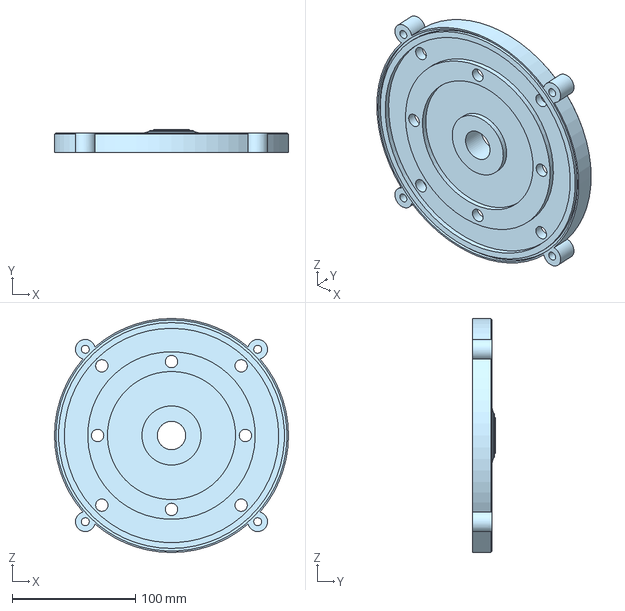
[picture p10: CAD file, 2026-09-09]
CAD/Tower Lid.step
190.0 x 19.0 x 190.0 mm

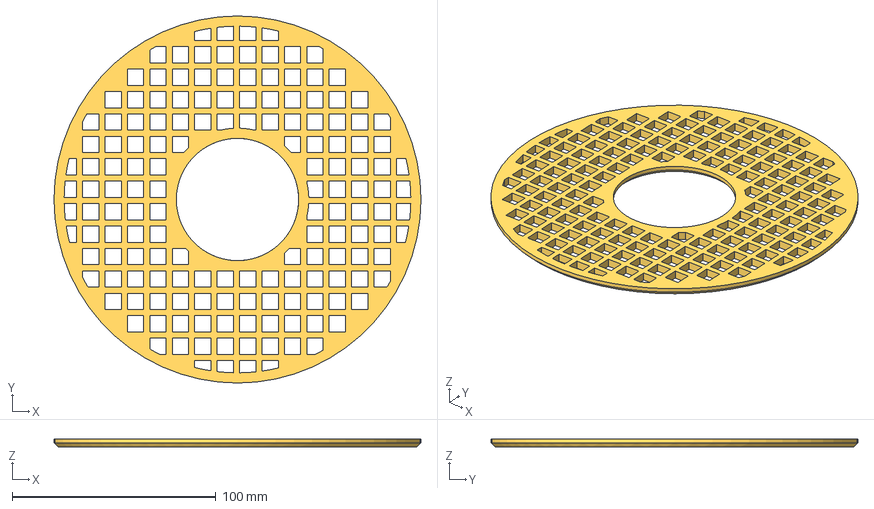
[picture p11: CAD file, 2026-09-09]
CAD/Root Grate.step
180.0 x 180.0 x 4.00 mm

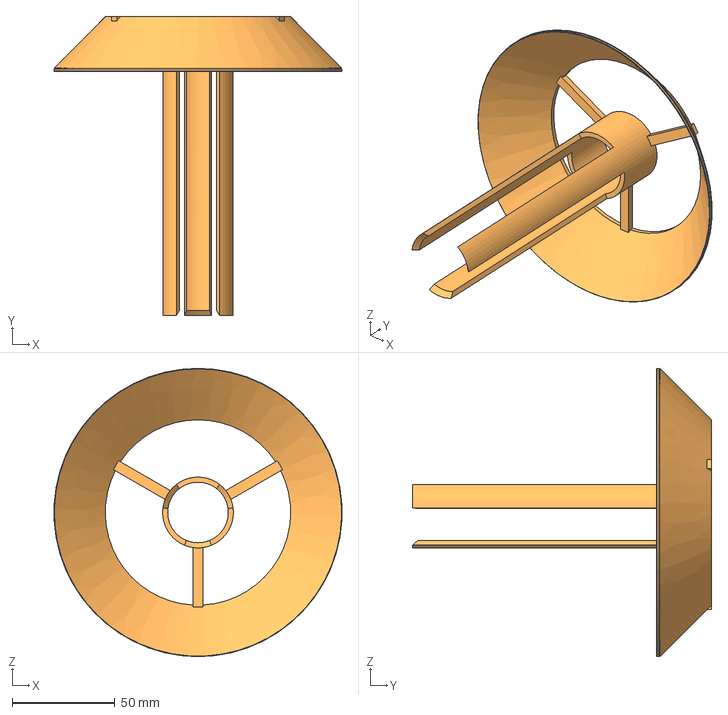
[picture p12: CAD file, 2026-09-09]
CAD/Water Spreader.step
139.8 x 145.2 x 140.0 mm

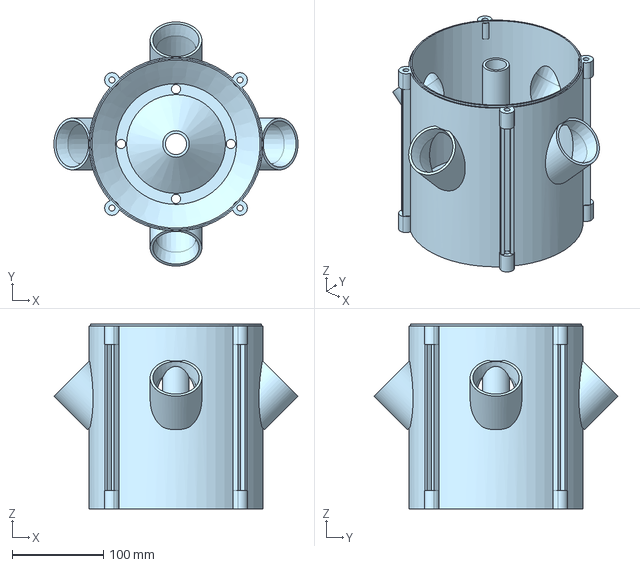
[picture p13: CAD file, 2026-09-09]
CAD/Grow Module.step
266.7 x 266.7 x 202.2 mm

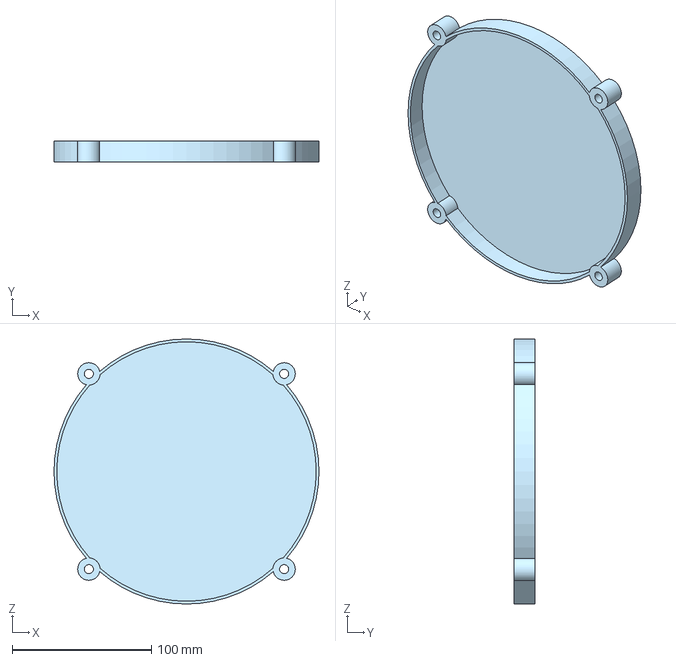
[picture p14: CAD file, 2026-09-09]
CAD/Lid Cap.step
190.0 x 15.0 x 190.0 mm

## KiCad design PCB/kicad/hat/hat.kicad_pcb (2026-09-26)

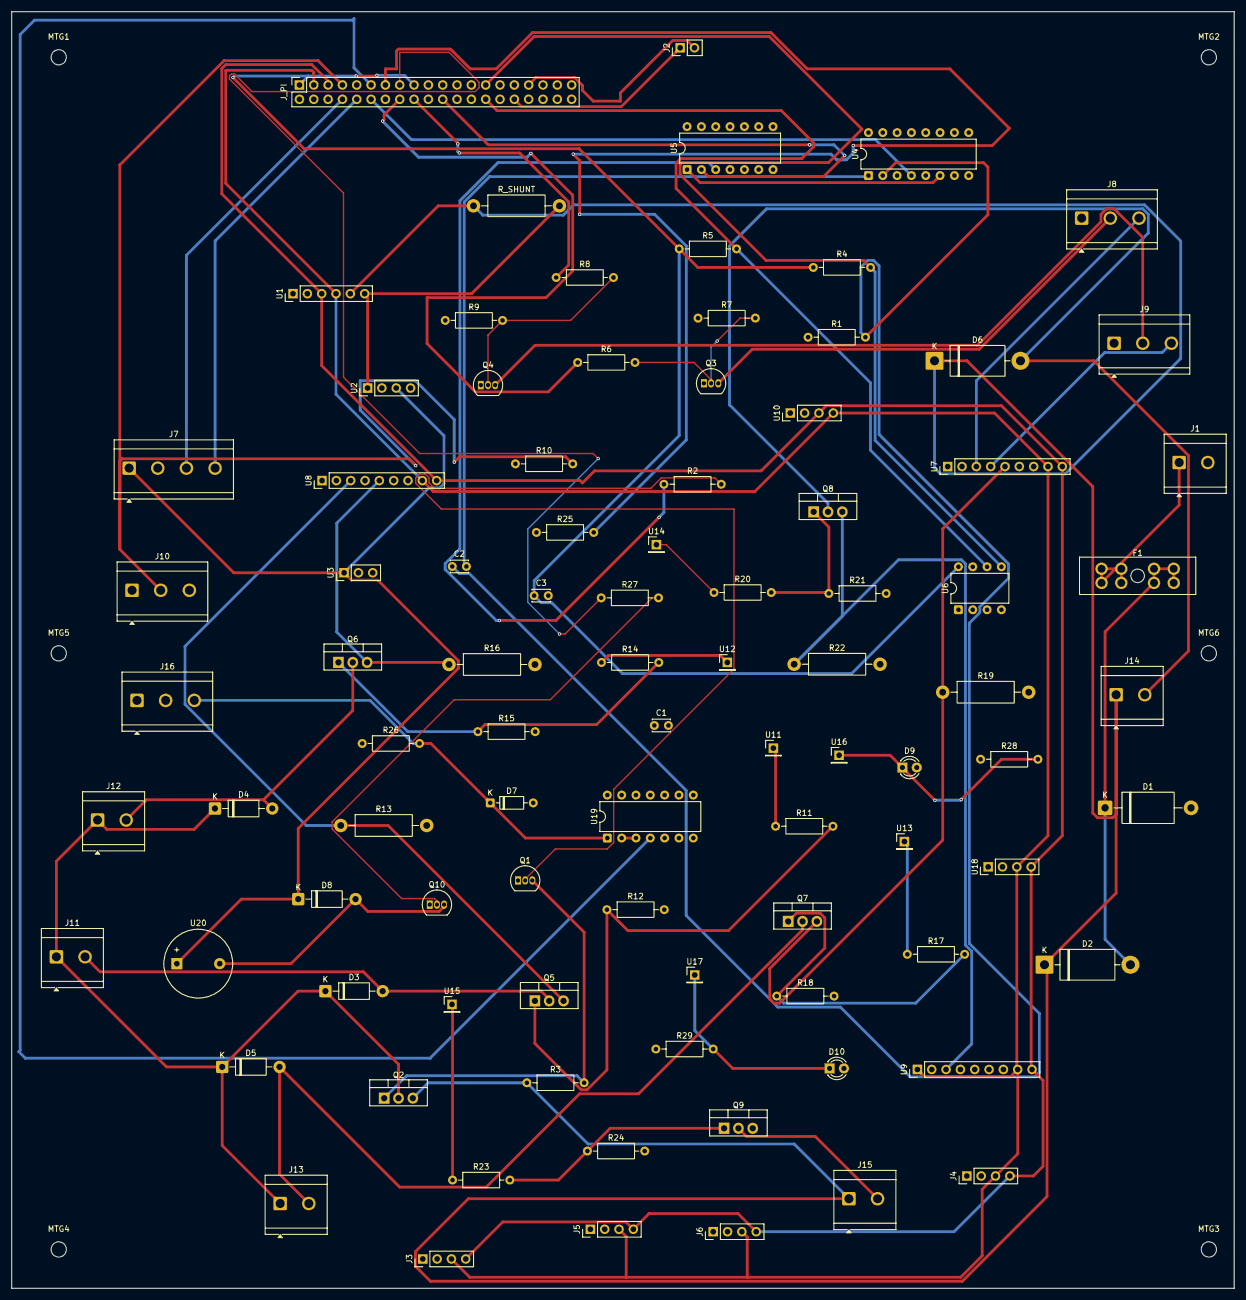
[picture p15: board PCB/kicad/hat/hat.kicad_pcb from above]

Board: 4 copper layers, 216.8 x 226.3 mm, 97 parts (0 on the bottom side), 62 nets.

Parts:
C1, C3: 100n; C_Disc_D3.0mm_W2.0mm_P2.50mm
C2: 10u 10V; C_Disc_D3.0mm_W2.0mm_P2.50mm
D1: 1.5KE15A; D_DO-201AE_P15.24mm_Horizontal
D2: SB5H100; D_DO-201AD_P15.24mm_Horizontal
D3, D4, D5, D8: 1N5819; D_DO-41_SOD81_P10.16mm_Horizontal
D6: 1N5822; D_DO-201AD_P15.24mm_Horizontal
D7: 1N4148; D_DO-35_SOD27_P7.62mm_Horizontal
D9: rail; LED_D3.0mm
D10: pump; LED_D3.0mm
F1: 10A; FuseHolder_Blade_ATO_Littelfuse_FLR_178.6165
J1: 12V IN; TerminalBlock_CUI_TB007-508-02_1x02_P5.08mm_Horizontal
J2: spare gpio; PinHeader_1x02_P2.54mm_Vertical
J3: sht31 module; PinHeader_1x04_P2.54mm_Vertical
J4: veml7700 module; PinHeader_1x04_P2.54mm_Vertical
J5: scd40 module; PinHeader_1x04_P2.54mm_Vertical
J6: oled ssd1306; PinHeader_1x04_P2.54mm_Vertical
J7: JSN-SR04T (uart mode); TerminalBlock_CUI_TB007-508-04_1x04_P5.08mm_Horizontal
J8: pH board; Gravity_TB3
J9: EC board; Gravity_TB3
J10: DS18B20; TerminalBlock_CUI_TB007-508-03_1x03_P5.08mm_Horizontal
J11: pump 1; TerminalBlock_CUI_TB007-508-02_1x02_P5.08mm_Horizontal
J12: pump 2; TerminalBlock_CUI_TB007-508-02_1x02_P5.08mm_Horizontal
J13: pump 3; TerminalBlock_CUI_TB007-508-02_1x02_P5.08mm_Horizontal
J14: led strip; TerminalBlock_CUI_TB007-508-02_1x02_P5.08mm_Horizontal
J15: fan; TerminalBlock_CUI_TB007-508-02_1x02_P5.08mm_Horizontal
J16: flow sensor; TerminalBlock_CUI_TB007-508-03_1x03_P5.08mm_Horizontal
J_PI: Pi 5, 40 pin (tall stacking header); PinSocket_2x20_P2.54mm_Vertical
MTG1, MTG2, MTG3, MTG4, MTG5, MTG6: MountingHole; MountingHole_2.7mm_M2.5
Q1, Q10: 2N7000; TO-92_Inline
Q2: IRF9540N; TO-220-3_Vertical
Q3, Q4: BS250; TO-92_Inline
Q5, Q6, Q7, Q8, Q9: IRLZ44N; TO-220-3_Vertical
R1: 470k; R_Axial_DIN0207_L6.3mm_D2.5mm_P10.16mm_Horizontal
R2, R6, R8, R27, R28, R29: 1k; R_Axial_DIN0207_L6.3mm_D2.5mm_P10.16mm_Horizontal
R3, R4, R5, R7, R9, R12, R15, R18, R21, R24, R25, R26: 10k; R_Axial_DIN0207_L6.3mm_D2.5mm_P10.16mm_Horizontal
R10: 4k7; R_Axial_DIN0207_L6.3mm_D2.5mm_P10.16mm_Horizontal
R11, R14, R17, R20, R23: 100R; R_Axial_DIN0207_L6.3mm_D2.5mm_P10.16mm_Horizontal
R13, R16, R19: 0.1; R_Axial_DIN0411_L9.9mm_D3.6mm_P15.24mm_Horizontal
R22: 0.01; R_Axial_DIN0411_L9.9mm_D3.6mm_P15.24mm_Horizontal
R_SHUNT: 5m; R_Axial_DIN0411_L9.9mm_D3.6mm_P15.24mm_Horizontal
U1: INA226 module 0x40; PinHeader_1x06_P2.54mm_Vertical
U2: buck module 12V->5V; PinHeader_1x04_P2.54mm_Vertical
U3: AMS1117 3.3V module; PinHeader_1x03_P2.54mm_Vertical
U4: CD4538; DIP-16_W7.62mm
U5: CD4081; DIP-14_W7.62mm
U6: 24LC32A/P; DIP-8_W7.62mm
U7: ADS1115 module 0x48 (ph/ec + pump3 diff); PinHeader_1x09_P2.54mm_Vertical
U8: ADS1115 module 0x49 (pump1/pump2 diff); PinHeader_1x09_P2.54mm_Vertical
U9: ADS1115 module 0x4A (led diff); PinHeader_1x09_P2.54mm_Vertical
U10: PCA9685 module (i2c); PinHeader_1x04_P2.54mm_Vertical
U11: PCA9685 ch0 (pump1 pwm); PinHeader_1x01_P2.54mm_Vertical
U12: PCA9685 ch1 (pump2 pwm); PinHeader_1x01_P2.54mm_Vertical
U13: PCA9685 ch2 (pump3 pwm); PinHeader_1x01_P2.54mm_Vertical
U14: PCA9685 ch3 (led pwm); PinHeader_1x01_P2.54mm_Vertical
U15: PCA9685 ch4 (fan pwm); PinHeader_1x01_P2.54mm_Vertical
U16: PCA9685 ch5 (rail status led); PinHeader_1x01_P2.54mm_Vertical
U17: PCA9685 ch6 (pump status led); PinHeader_1x01_P2.54mm_Vertical
U18: DS3231 RTC module; PinHeader_1x04_P2.54mm_Vertical
U19: CD40106; DIP-14_W7.62mm
U20: 5V active; Buzzer_12x9.5RM7.6

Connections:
12V_F: D1.1, D2.2, F1.2
+3V3: C1.1, J3.1, J4.1, J5.1, J6.1, J10.3, J16.1, Q3.1, Q4.1, R1.1, R7.1, R9.1, R10.1, R25.1, R26.1, R28.1, R29.1, U1.2, U3.3, U4.3, U4.13, U4.16, U5.14, U7.7, U8.1, U8.7, U9.7, U10.1, U18.1, U19.14
+3V3_PI: C3.1, J_PI.1, J_PI.17, R4.1, R5.1, U6.8
+5V: D8.1, J7.1, U2.3, U3.1, U20.1
+12V: D2.1, D6.1, J14.1, J15.1, Q2.3, R3.1, R_SHUNT.1, U1.5
+12V_DOSE: D3.1, D4.1, D5.1, J11.1, J12.1, J13.1, Q2.2
+12V_RAW: F1.1, J1.1
+12V_S: R_SHUNT.2, U1.6, U2.1
/ARM: J_PI.22, U5.2
/BUZZ: J_PI.15, R27.1
/EC_EN: J_PI.18, R8.1
/EC_S: J9.3, U7.4
/EC_VCC_SW: J9.1, Q4.3
/EEPROM_SCL: J_PI.28, R5.2, U6.6
/EEPROM_SDA: J_PI.27, R4.2, U6.5
/FAN_G: Q9.1, R23.2, R24.1
/FAN_N: J15.2, Q9.2
/FAN_PWM: R23.1, U15.1
/FAN_TACH: J_PI.13, R25.2
/FLOW: J_PI.11, U19.4
/FLOW_RAW: D7.1, J16.3, R26.2, U19.1
/HB_ALIVE: J_PI.12, U4.4
/LED_G: Q8.1, R20.2, R21.1
/LED_N: D6.2, J14.2, Q8.2
/LED_PWM: R20.1, U14.1
/LED_S: Q8.3, R22.1, U9.3
/LED_STAT_PUMP: D10.1, R29.2, U17.1
/LED_STAT_RAIL: D9.1, R28.2, U16.1
/PH_EN: J_PI.16, R6.1
/PH_S: J8.3, U7.3
/PH_VCC_SW: J8.1, Q3.3
/PUMP1_G: Q5.1, R11.2, R12.1
/PUMP1_N: D3.2, J11.2, Q5.2
/PUMP1_PWM: R11.1, U11.1
/PUMP1_S: Q5.3, R13.1, U8.3
/PUMP2_G: Q6.1, R14.2, R15.1
/PUMP2_N: D4.2, J12.2, Q6.2
/PUMP2_PWM: R14.1, U12.1
/PUMP2_S: Q6.3, R16.1, U8.5
/PUMP3_G: Q7.1, R17.2, R18.1
/PUMP3_N: D5.2, J13.2, Q7.2
/PUMP3_PWM: R17.1, U13.1
/PUMP3_S: Q7.3, R19.1, U7.5
/RAIL_EN: R2.1, U5.3
/RAIL_EN_R: Q1.2, R2.2
/RAIL_G: Q1.3, Q2.1, R3.2
/SCL: J3.4, J4.4, J5.4, J6.4, J_PI.5, U1.3, U7.9, U8.9, U9.9, U10.3, U18.4
/SDA: J3.3, J4.3, J5.3, J6.3, J_PI.3, U1.4, U7.8, U8.8, U9.1, U9.8, U10.4, U18.3
/SONAR_RX: J7.4, J_PI.10
/SONAR_TX: J7.3, J_PI.8
/SPARE_GPIO12: J2.1, J_PI.32
/SPARE_GPIO13: J2.2, J_PI.33
/W1: J10.2, J_PI.7, R10.2
BUZZ_G: Q10.2, R27.2
BUZZ_N: D8.2, Q10.3, U20.2
EC_G: Q4.2, R8.2, R9.2
FLOW_INV: U19.2, U19.3
GND: C1.2, C3.2, D1.2, D7.2, D9.2, D10.2, J1.2, J3.2, J4.2, J5.2, J6.2, J7.2, J8.2, J9.2, J10.1, J16.2, J_PI.6, J_PI.9, J_PI.14, J_PI.20, J_PI.25, J_PI.30, J_PI.34, J_PI.39, Q1.1, Q9.3, Q10.1, R12.2, R13.2, R15.2, R16.2, R18.2, R19.2, R21.2, R22.2, R24.2, U1.1, U2.2, U2.4, U3.2, U4.5, U4.8, U4.11, U4.12, U5.5, U5.6, U5.7, U5.8, U5.9, U5.12, U5.13, U6.1, U6.2, U6.3, U6.4, U7.1, U7.2, U7.6, U8.2, U8.4, U8.6, U9.2, U9.4, U10.2, U18.2, U19.5, U19.7, U19.9, U19.11, U19.13
MONO_CEXT: C2.2, U4.1
MONO_Q: U4.6, U5.1
MONO_RC: C2.1, R1.2, U4.2
PH_G: Q3.2, R6.2, R7.2

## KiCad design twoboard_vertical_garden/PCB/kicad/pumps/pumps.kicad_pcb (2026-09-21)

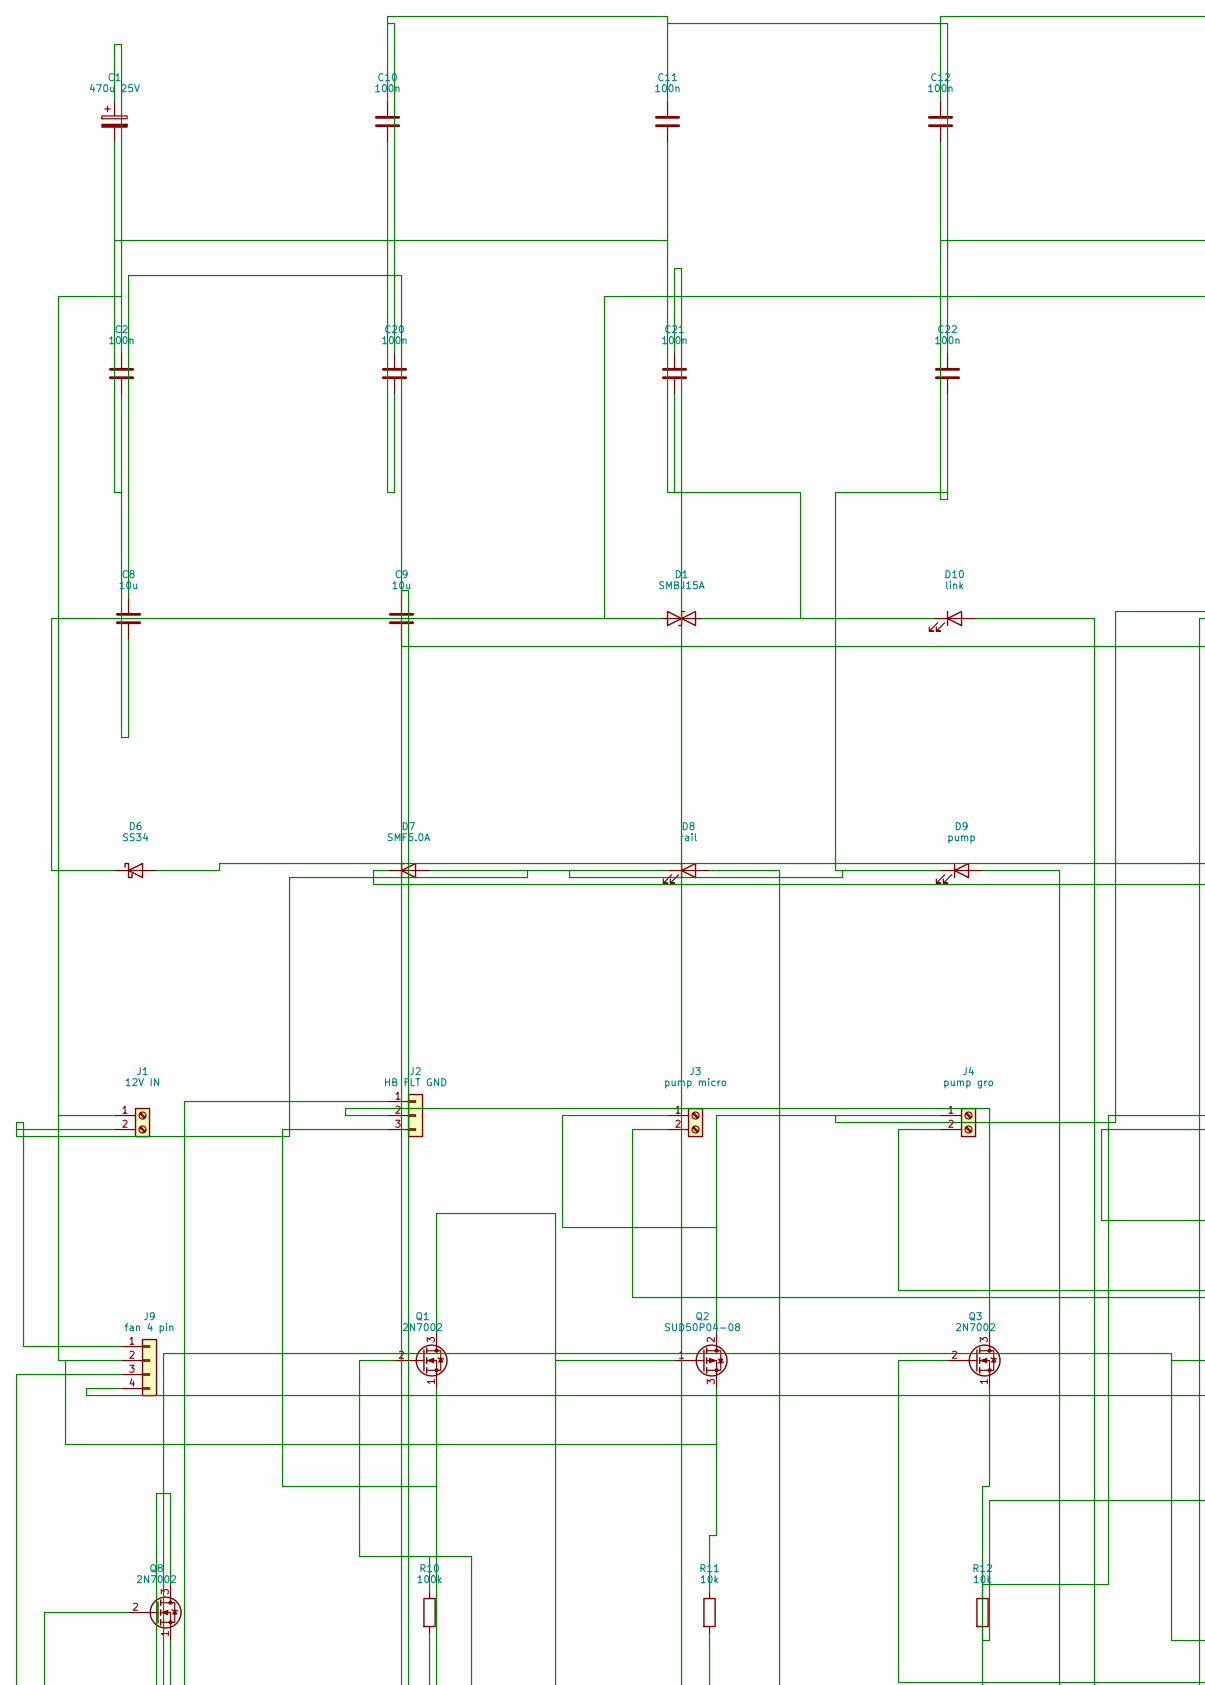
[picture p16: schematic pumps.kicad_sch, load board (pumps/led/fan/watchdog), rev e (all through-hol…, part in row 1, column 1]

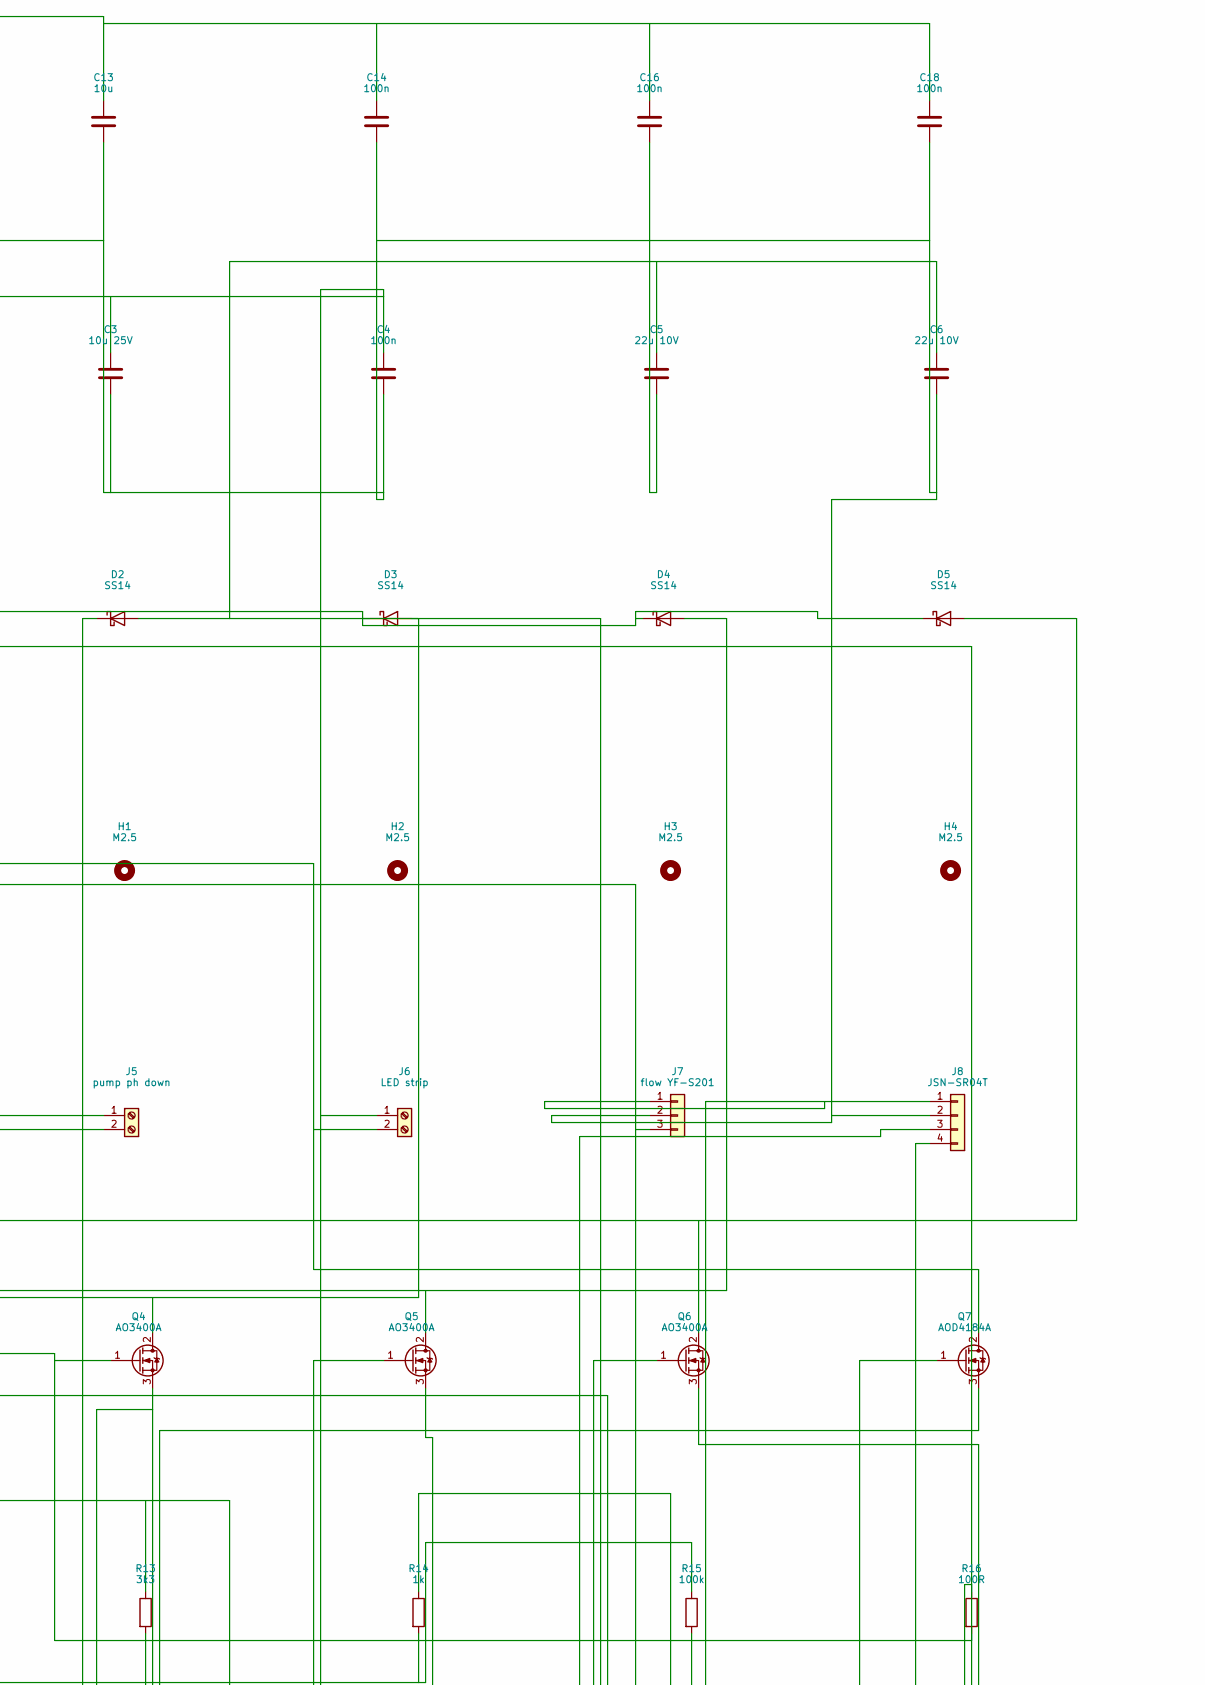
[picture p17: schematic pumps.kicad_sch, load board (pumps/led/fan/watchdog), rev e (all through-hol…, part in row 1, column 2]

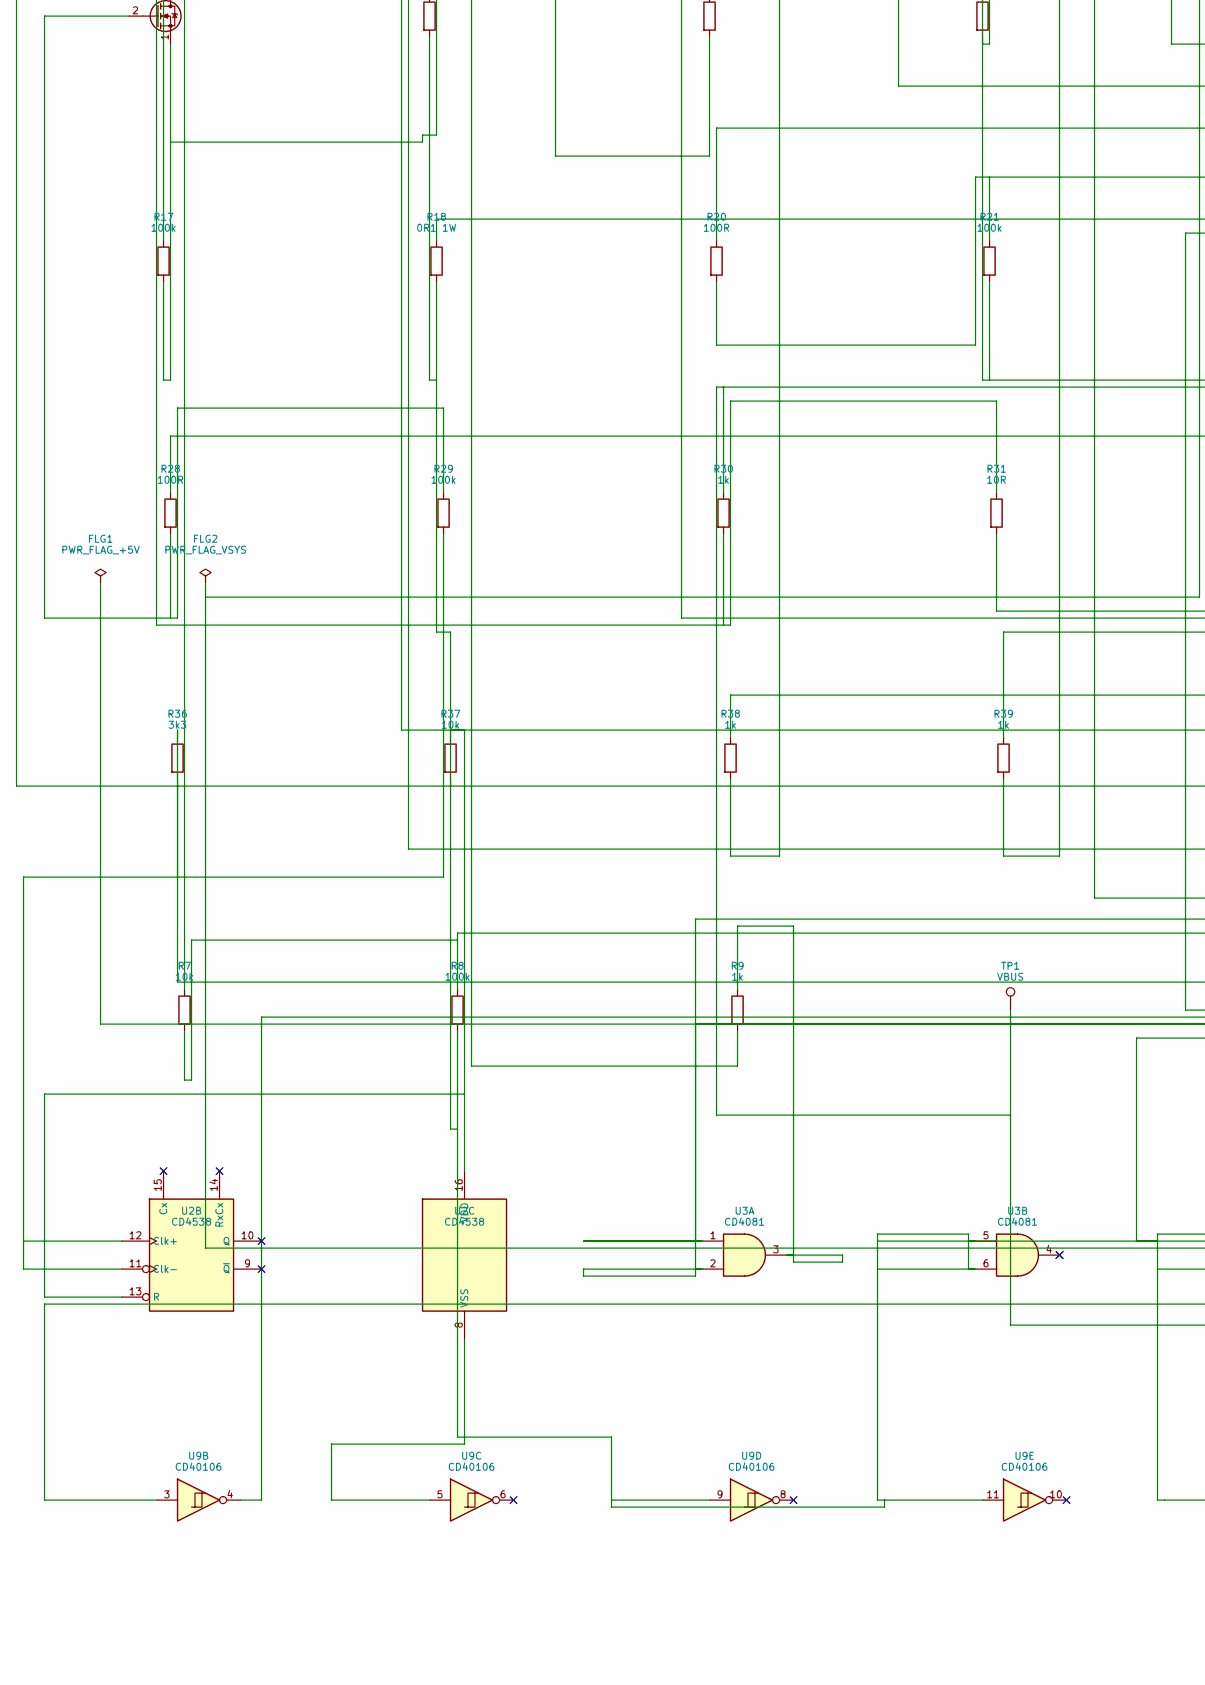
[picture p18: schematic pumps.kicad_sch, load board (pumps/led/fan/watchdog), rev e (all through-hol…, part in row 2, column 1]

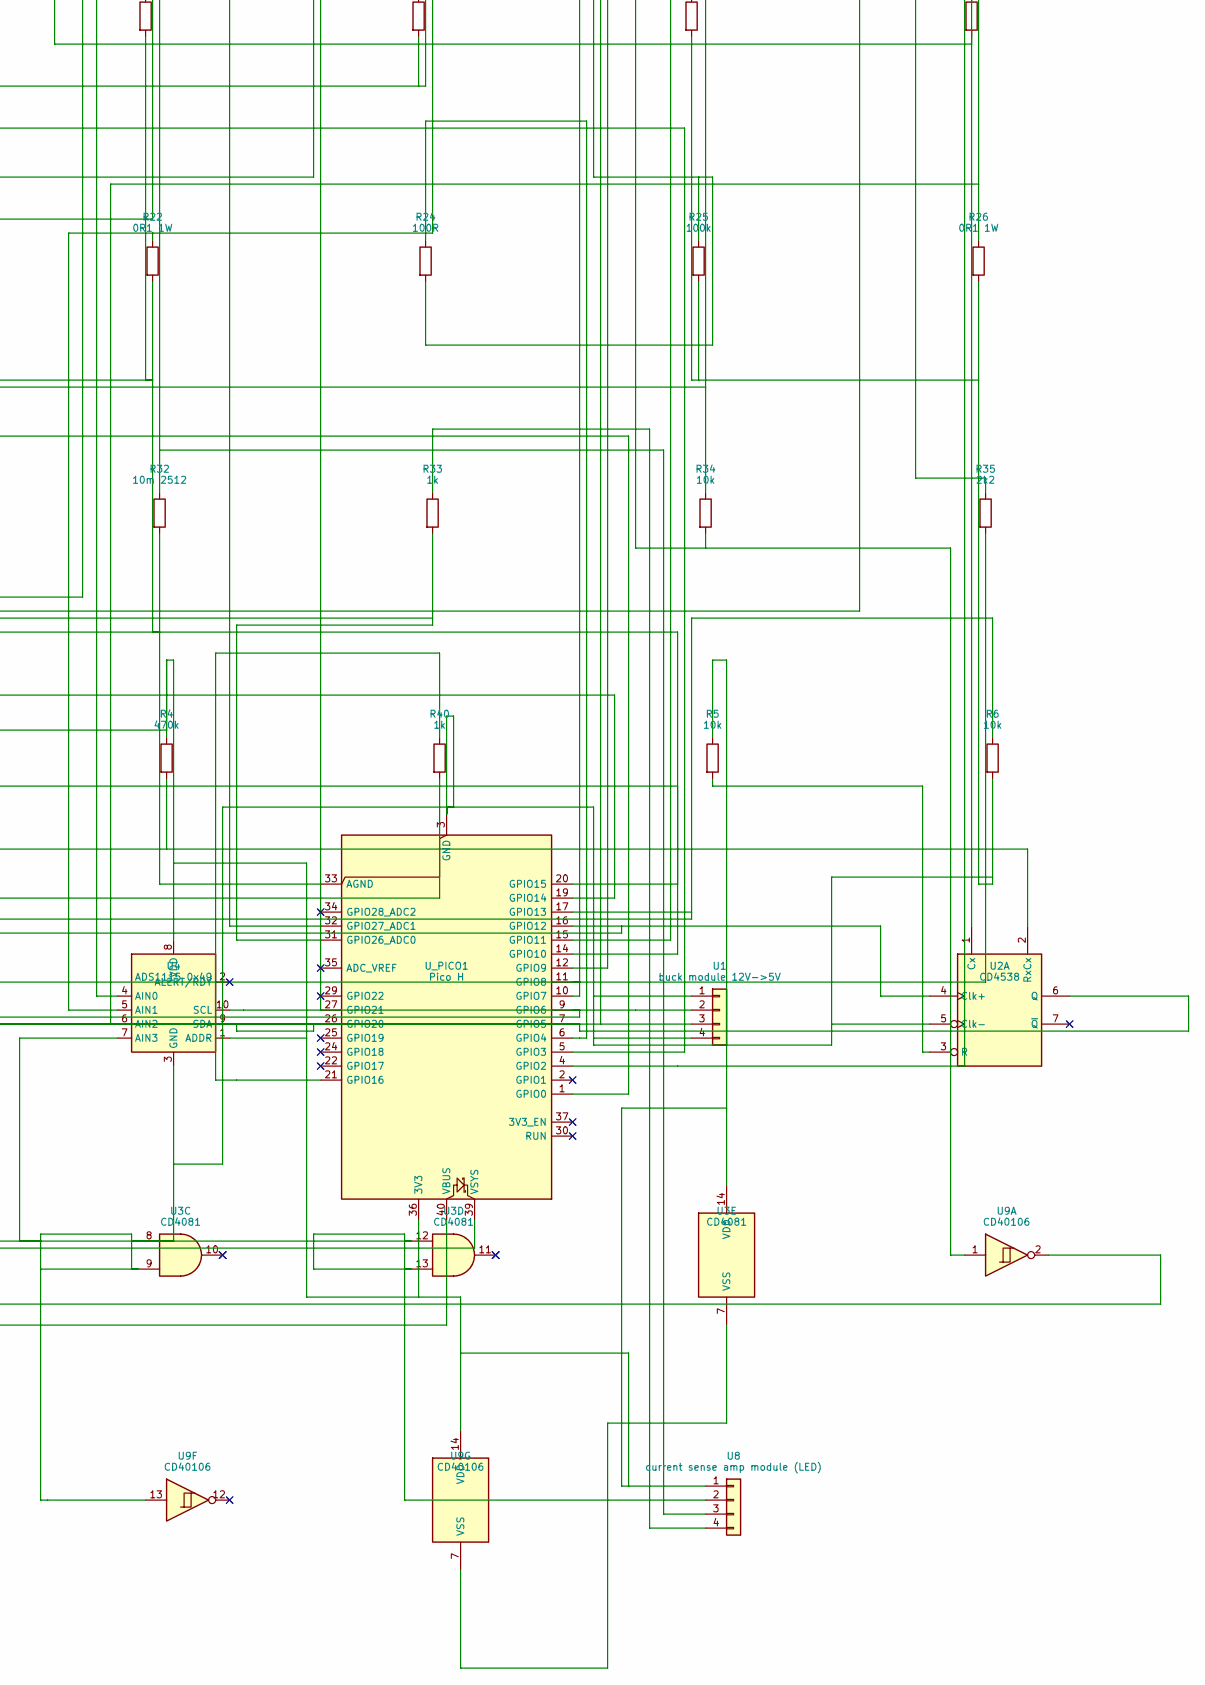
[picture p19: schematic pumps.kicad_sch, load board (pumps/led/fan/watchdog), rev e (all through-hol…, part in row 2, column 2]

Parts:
C1: 470u 25V; CP_Radial_D10.0mm_P5.00mm
C2, C4, C10, C11, C12, C14, C16, C18, C20, C21, C22: 100n; C_Disc_D3.0mm_W2.0mm_P2.50mm
C3: 10u 25V; C_Disc_D5.0mm_W2.5mm_P5.00mm
C5, C6: 22u 10V; C_Disc_D5.0mm_W2.5mm_P5.00mm
C8, C9, C13: 10u; C_Disc_D5.0mm_W2.5mm_P5.00mm
D1: SMBJ15A; D_DO-201AE_P15.24mm_Horizontal
D2, D3, D4, D5: SS14; D_DO-41_SOD81_P10.16mm_Horizontal
D6: SS34; D_DO-41_SOD81_P10.16mm_Horizontal
D7: SMF5.0A; D_DO-35_SOD27_P7.62mm_Horizontal
D8: rail; LED_D3.0mm
D9: pump; LED_D3.0mm
D10: link; LED_D3.0mm
FLG1: PWR_FLAG_+5V
FLG2: PWR_FLAG_VSYS
H1, H2, H3, H4: M2.5; MountingHole_2.7mm_M2.5
J1: 12V IN; TerminalBlock_CUI_TB007-508-02_1x02_P5.08mm_Horizontal
J2: HB FLT GND; JST_XH_B3B-XH-A_1x03_P2.50mm_Vertical
J3: pump micro; TerminalBlock_CUI_TB007-508-02_1x02_P5.08mm_Horizontal
J4: pump gro; TerminalBlock_CUI_TB007-508-02_1x02_P5.08mm_Horizontal
J5: pump ph down; TerminalBlock_CUI_TB007-508-02_1x02_P5.08mm_Horizontal
J6: LED strip; TerminalBlock_CUI_TB007-508-02_1x02_P5.08mm_Horizontal
J7: flow YF-S201; JST_XH_B3B-XH-A_1x03_P2.50mm_Vertical
J8: JSN-SR04T; JST_XH_B4B-XH-AM_1x04_P2.50mm_Vertical
J9: fan 4 pin; FanPinHeader_1x04_P2.54mm_Vertical
Q1, Q3, Q8: 2N7002; TO-92_Inline
Q2: SUD50P04-08; TO-220-3_Vertical
Q4, Q5, Q6: AO3400A; TO-220-3_Vertical
Q7: AOD4184A; TO-220-3_Vertical
R4: 470k; R_Axial_DIN0207_L6.3mm_D2.5mm_P10.16mm_Horizontal
R5, R6, R7, R11, R12, R34, R37: 10k; R_Axial_DIN0207_L6.3mm_D2.5mm_P10.16mm_Horizontal
R8, R10, R15, R17, R21, R25, R29: 100k; R_Axial_DIN0207_L6.3mm_D2.5mm_P10.16mm_Horizontal
R9, R14, R30, R33, R38, R39, R40: 1k; R_Axial_DIN0207_L6.3mm_D2.5mm_P10.16mm_Horizontal
R13, R36: 3k3; R_Axial_DIN0207_L6.3mm_D2.5mm_P10.16mm_Horizontal
R16, R20, R24, R28: 100R; R_Axial_DIN0207_L6.3mm_D2.5mm_P10.16mm_Horizontal
R18, R22, R26: 0R1 1W; R_Axial_DIN0207_L6.3mm_D2.5mm_P10.16mm_Horizontal
R31: 10R; R_Axial_DIN0207_L6.3mm_D2.5mm_P10.16mm_Horizontal
R32: 10m 2512; R_Axial_DIN0411_L9.9mm_D3.6mm_P15.24mm_Horizontal
R35: 2k2; R_Axial_DIN0207_L6.3mm_D2.5mm_P10.16mm_Horizontal
TP1: VBUS; TestPoint_Pad_D1.5mm
U1: buck module 12V->5V; PinHeader_1x04_P2.54mm_Vertical
U2: CD4538; DIP-16_W7.62mm
U3: CD4081; DIP-14_W7.62mm
U4: ADS1115 0x49; ADS1115_Module
U8: current sense amp module (LED); PinHeader_1x04_P2.54mm_Vertical
U9: CD40106; DIP-14_W7.62mm
U_PICO1: Pico H; RaspberryPi_Pico_Common_THT

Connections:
+3V3: C8.1, C10.1, C11.1, C12.1, C13.1, C14.1, C16.1, C18.1, C20.1, C22.1, R4.1, R5.1, R37.1, U2.13 (R), U2.16 (VDD), U3.14 (VDD), U4.1 (ADDR), U4.8 (VDD), U8.1, U9.14 (VDD), U_PICO1.36 (3V3)
+5V: C5.1, C6.1, D2.2 (A), FLG1.1, U1.3
/12V_DOSE: D3.1 (K), D4.1 (K), D5.1 (K), J3.1, J4.1, J5.1, Q2.2 (D), R12.1
/ARM: R6.1, U3.2, U_PICO1.17 (GPIO13)
/FAN_PWM: J9.4, U_PICO1.12 (GPIO9)
/FAN_TACH: J9.3, R37.2, U_PICO1.14 (GPIO10)
/FLOW: U9.4, U_PICO1.9 (GPIO6)
/FLT: J2.2, Q3.3 (D)
/FLT_DRV: R14.1, U_PICO1.15 (GPIO11)
/HB: J2.1, R7.1
/HB_IN: R7.2, R8.1, U2.4 (Clk+), U_PICO1.16 (GPIO12)
/LDRV_D: Q8.3 (D), R30.2, R31.1
/LED_ISENSE: C21.1, R33.2, U_PICO1.31 (GPIO26_ADC0)
/LED_LINK: R40.1, U_PICO1.21 (GPIO16)
/LED_N: D6.2 (A), J6.2, Q7.2 (D)
/LED_PUMP: R39.1, U_PICO1.20 (GPIO15)
/LED_PWM_N: R28.1, U_PICO1.1 (GPIO0)
/LED_RAIL: R38.1, U_PICO1.19 (GPIO14)
/MONO_CLR: R5.2, U2.3 (R)
/MONO_RC: C9.1, R4.2, U2.2 (RxCx)
/PUMP1_EN: R16.1, U_PICO1.4 (GPIO2)
/PUMP2_EN: R20.1, U_PICO1.5 (GPIO3)
/PUMP2_SH: Q5.3 (S), R22.1, U4.5 (AIN1)
/PUMP3_EN: R24.1, U_PICO1.6 (GPIO4)
/PUMP3_G: Q6.1 (G), R24.2, R25.1
/PUMP3_N: D5.2 (A), J5.2, Q6.2 (D)
/PUMP3_SH: Q6.3 (S), R26.1, U4.6 (AIN2)
/RAIL_12V_SENSE: R12.2, R13.1, U_PICO1.32 (GPIO27_ADC1)
/RAIL_EN: R9.1, U3.3
/RAIL_G: Q1.3 (D), Q2.1 (G), R11.2
/SDA: U4.9 (SDA), U_PICO1.26 (GPIO20)
/SONAR_ECHO: R35.2, R36.1, U_PICO1.11 (GPIO8)
/SONAR_TRIG: J8.3, U_PICO1.10 (GPIO7)
FLOW_INV: U9.2, U9.3
GND: C1.2, C2.2, C3.2, C4.2, C5.2, C6.2, C8.2, C10.2, C11.2, C12.2, C13.2, C14.2, C16.2, C18.2, C20.2, C21.2, C22.2, D1.2 (A2), D7.2 (A), D8.1 (K), D9.1 (K), D10.1 (K), J1.2, J2.3, J7.2, J8.2, J9.1, Q1.1 (S), Q3.1 (S), Q8.1 (S), R6.2, R8.2, R10.2, R13.2, R15.2, R17.2, R18.2, R21.2, R22.2, R25.2, R26.2, R29.2, R32.2, R36.2, U1.1, U1.4, U2.5 (Clk-), U2.8 (VSS), U2.11 (Clk-), U2.12 (Clk+), U3.5, U3.6, U3.7 (VSS), U3.8, U3.9, U3.12, U3.13, U4.3 (GND), U4.7 (AIN3), U8.2, U9.5, U9.7 (VSS), U9.9, U9.11, U9.13, U_PICO1.3 (GND), U_PICO1.8 (GND), U_PICO1.13 (GND), U_PICO1.18 (GND), U_PICO1.23 (GND), U_PICO1.28 (GND), U_PICO1.33 (AGND), U_PICO1.38 (GND)
unnamed: D3.2 (A), J3.2, Q4.2 (D)
unnamed: D4.2 (A), J4.2, Q5.2 (D)
unnamed: D7.1 (K), J7.3, R34.2, U9.1
unnamed: D8.2 (A), R38.2
unnamed: D9.2 (A), R39.2
unnamed: D10.2 (A), R40.2
unnamed: J8.4, R35.1
unnamed: Q1.2 (G), R9.2, R10.1
unnamed: Q3.2 (G), R14.2, R15.1
unnamed: Q4.1 (G), R16.2, R17.1
unnamed: Q4.3 (S), R18.1, U4.4 (AIN0)
unnamed: Q5.1 (G), R20.2, R21.1
unnamed: Q7.1 (G), R31.2
unnamed: Q7.3 (S), R32.1, U8.3
unnamed: Q8.2 (G), R28.2, R29.1
unnamed: R33.1, U8.4
unnamed: C9.2, U2.1 (Cx)
unnamed: U2.6 (Q), U3.1, U_PICO1.7 (GPIO5)
VBUS: J7.1, J8.1, R30.1, R34.1, TP1.1, U_PICO1.40 (VBUS)
VSYS: D2.1 (K), FLG2.1, U_PICO1.39 (VSYS)

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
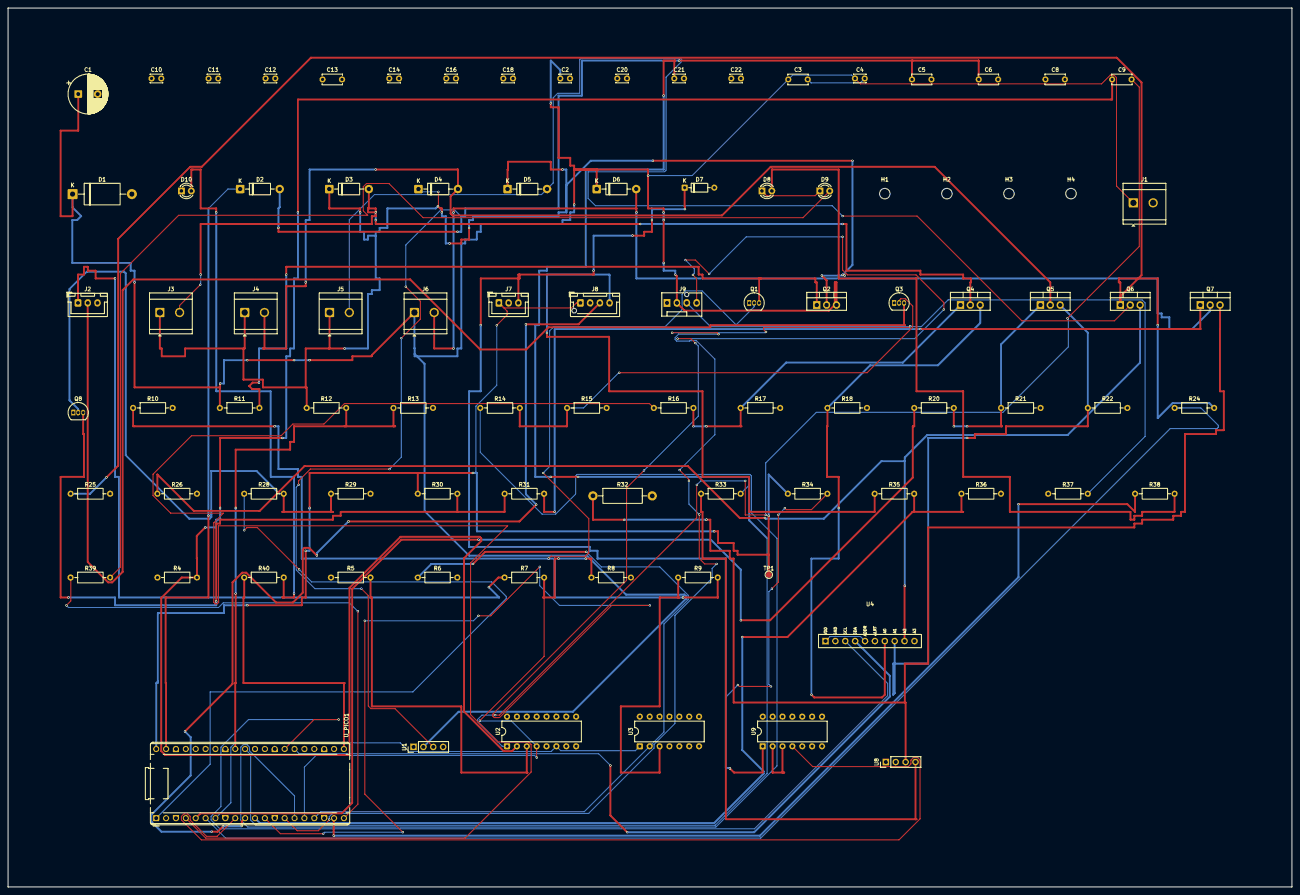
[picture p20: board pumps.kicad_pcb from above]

Board: 4 copper layers, 330.0 x 225.9 mm, 91 parts (0 on the bottom side), 57 nets.

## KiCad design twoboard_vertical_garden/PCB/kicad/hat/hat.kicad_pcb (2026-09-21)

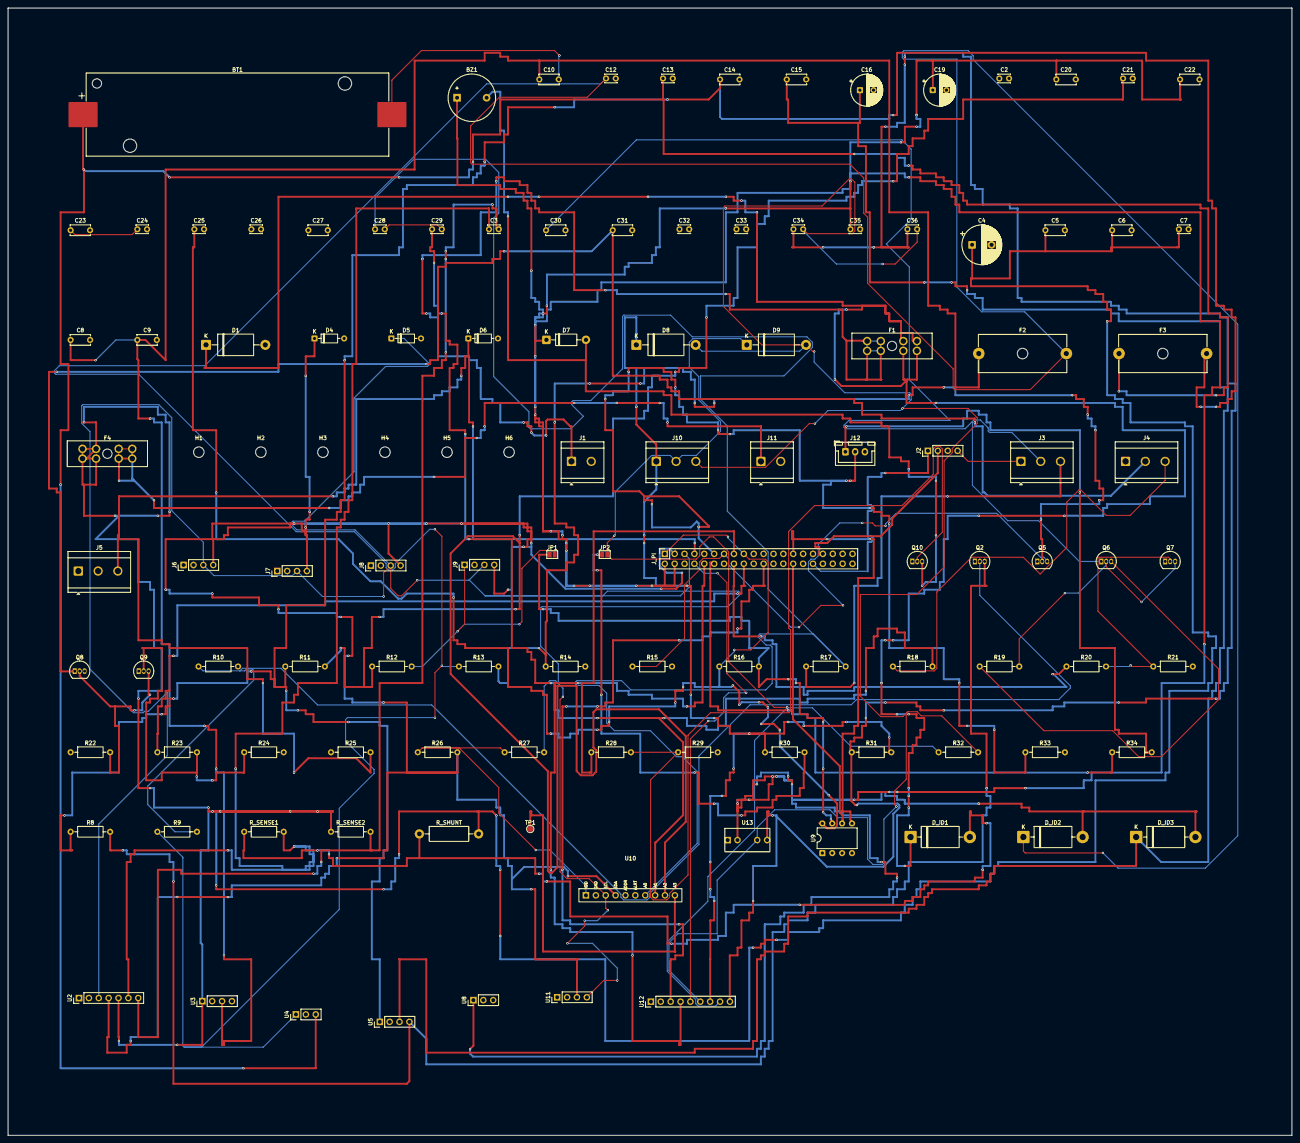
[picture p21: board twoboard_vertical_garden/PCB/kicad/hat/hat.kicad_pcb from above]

Board: 4 copper layers, 330.0 x 289.7 mm, 117 parts (0 on the bottom side), 56 nets.

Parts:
BT1: 18650 protected; BatteryHolder_Keystone_1042_1x18650
BZ1: active 5V; Buzzer_12x9.5RM7.6
C2, C3, C7, C21, C24, C25, C26, C28, C29, C32, C33, C34: 100n; C_Disc_D3.0mm_W2.0mm_P2.50mm
C4: 470u 25V; CP_Radial_D10.0mm_P5.00mm
C5, C6: 10u 25V; C_Disc_D5.0mm_W2.5mm_P5.00mm
C8, C9, C10, C14, C15, C20, C23: 22u 10V; C_Disc_D5.0mm_W2.5mm_P5.00mm
C12, C13, C35, C36: 4u7; C_Disc_D3.0mm_W2.0mm_P2.50mm
C16: 220u 10V; CP_Radial_D8.0mm_P3.50mm
C19: 470u 10V; CP_Radial_D8.0mm_P3.50mm
C22, C27, C30, C31: 10u; C_Disc_D5.0mm_W2.5mm_P5.00mm
D1: SMBJ15A; D_DO-201AE_P15.24mm_Horizontal
D4, D5, D6: SMF5.0A; D_DO-35_SOD27_P7.62mm_Horizontal
D7: SS14; D_DO-41_SOD81_P10.16mm_Horizontal
D8, D9: SMAJ6.5CA; D_DO-201AE_P15.24mm_Horizontal
D_ID1, D_ID2, D_ID3: SB5H100; D_DO-201AD_P15.24mm_Horizontal
F1: 10A blade; FuseHolder_Blade_ATO_Littelfuse_FLR_178.6165
F2, F3: 3A; Fuseholder_Cylinder-5x20mm_Schurter_0031_8201_Horizontal_Op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
F4: 7.5A blade; FuseHolder_Blade_ATO_Littelfuse_FLR_178.6165
H1, H2, H3, H4, H5, H6: M2.5; MountingHole_2.7mm_M2.5
J1: 12V IN; TerminalBlock_CUI_TB007-508-02_1x02_P5.08mm_Horizontal
J2: spare gpio; PinHeader_1x04_P2.54mm_Vertical
J3: pH board; Gravity_TB3
J4: EC board; Gravity_TB3
J5: DS18B20; TerminalBlock_CUI_TB007-508-03_1x03_P5.08mm_Horizontal
J6: sht31 module; PinHeader_1x04_P2.54mm_Vertical
J7: veml7700 module; PinHeader_1x04_P2.54mm_Vertical
J8: scd40 module; PinHeader_1x04_P2.54mm_Vertical
J9: oled ssd1306; PinHeader_1x04_P2.54mm_Vertical
J10: RS485 A B G; TerminalBlock_CUI_TB007-508-03_1x03_P5.08mm_Horizontal
J11: 12V OUT; TerminalBlock_CUI_TB007-508-02_1x02_P5.08mm_Horizontal
J12: HB FLT GND; JST_XH_B3B-XH-A_1x03_P2.50mm_Vertical
JP1: WP; SolderJumper-2_P1.3mm_Open_Pad1.0x1.5mm
JP2: term; SolderJumper-2_P1.3mm_Open_Pad1.0x1.5mm
J_PI: Pi 40 pin; PinSocket_2x20_P2.54mm_Vertical
Q2, Q5, Q7, Q9, Q10: 2N7002; TO-92_Inline
Q6, Q8: AO3401A; TO-92_Inline
R8, R9, R10, R11, R12, R13, R14, R21, R24, R29: 100k; R_Axial_DIN0207_L6.3mm_D2.5mm_P10.16mm_Horizontal
R15, R16, R19, R22, R33: 10k; R_Axial_DIN0207_L6.3mm_D2.5mm_P10.16mm_Horizontal
R17, R18, R20, R23, R28: 1k; R_Axial_DIN0207_L6.3mm_D2.5mm_P10.16mm_Horizontal
R25: 4k7; R_Axial_DIN0207_L6.3mm_D2.5mm_P10.16mm_Horizontal
R26, R27: 2k2; R_Axial_DIN0207_L6.3mm_D2.5mm_P10.16mm_Horizontal
R30: 120R; R_Axial_DIN0207_L6.3mm_D2.5mm_P10.16mm_Horizontal
R31, R32: 47k; R_Axial_DIN0207_L6.3mm_D2.5mm_P10.16mm_Horizontal
R34: 100R; R_Axial_DIN0207_L6.3mm_D2.5mm_P10.16mm_Horizontal
R_SENSE1, R_SENSE2: 10R; R_Axial_DIN0207_L6.3mm_D2.5mm_P10.16mm_Horizontal
R_SHUNT: 5m 2512; R_Axial_DIN0411_L9.9mm_D3.6mm_P15.24mm_Horizontal
TP1: AIN3; TestPoint_Pad_D1.5mm
U2: INA226 module 0x40; PinHeader_1x07_P2.54mm_Vertical
U3: buck module 12V->5V; PinHeader_1x04_P2.54mm_Vertical
U4: li-ion charger module (500mA); PinHeader_1x03_P2.54mm_Vertical
U5: XL6009 boost module (VBAT_F->5V); PinHeader_1x04_P2.54mm_Vertical
U8: AMS1117 3.3V module; PinHeader_1x03_P2.54mm_Vertical
U9: 24LC32A; DIP-8_W7.62mm
U10: ADS1115 module; ADS1115_Module
U11: DS3231 RTC module; PinHeader_1x04_P2.54mm_Vertical
U12: isolated RS485 module; PinHeader_1x09_P2.54mm_Vertical
U13: B0505S-1WR3; B0505S_SIP4

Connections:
12V_FUSED: D1.1, D_ID1.1, F1.2
+3V3: C2.1, C23.1, C24.1, C26.1, C27.1, C32.1, C33.1, J2.3, J5.1, J6.1, J7.1, J8.1, J9.2, Q6.3, Q8.3, R15.2, R19.1, R22.1, R25.1, R26.1, R27.1, R33.2, U2.2, U8.3, U10.8, U11.1, U12.1
+3V3_PI: C25.1, J_PI.1, J_PI.17, R16.1, U9.8
+5V: BZ1.1, C19.1, C20.1, C22.1, C35.1, D7.1, D_ID2.2, D_ID3.2, J_PI.2, J_PI.4, U8.1, U13.2
+5VISO: C34.1, C36.1, R31.1, U12.9, U13.4
+5V_BAT: C15.1, C16.1, D_ID3.1, U5.3
+5V_IN: C8.1, C9.1, C10.1, F2.1, U3.3
+5V_MAINS: C12.1, D_ID2.1, F2.2, R9.1, R13.1, U4.1
+12V: C4.1, C5.1, C6.1, C7.1, F4.1, R_SENSE2.1, R_SHUNT.2, U2.5, U3.1
+12V_IN: F1.1, J1.1
/12V_DIODE: D_ID1.2, R_SENSE1.1, R_SHUNT.1
/AIN3: TP1.1, U10.7
/BUZZ: J_PI.15, R28.1
/EC_ADC: C29.1, R18.2, U10.5
/EC_EN: J_PI.18, R23.1
/FLT: J12.2, J_PI.11, R33.1
/HB: J_PI.12, R34.1
/INA_INP: C3.1, R_SENSE1.2, U2.6
/MAINS_N: J_PI.13, Q5.3, R15.1
/PH_ADC: C28.1, R17.2, U10.4
/PH_EN: J_PI.16, R20.1
/RS485_DE: J_PI.22, U12.3
/RS485_RX: J_PI.10, U12.4
/RS485_TX: J_PI.8, U12.5
/SCL: D5.1, J6.3, J7.3, J8.3, J9.3, J_PI.5, R27.2, U2.3, U10.10, U11.4
/SDA: D4.1, J6.4, J7.4, J8.4, J9.4, J_PI.3, R26.2, U2.4, U10.9, U11.3
/VBAT_SENSE: C21.1, R11.2, R12.1, U10.6
/W1: D6.1, J5.3, J_PI.7, R25.2
EC_VCC: C31.1, J4.1, Q8.1
GND: BT1.2, C2.2, C4.2, C5.2, C6.2, C7.2, C8.2, C9.2, C10.2, C12.2, C13.2, C14.2, C15.2, C16.2, C19.2, C20.2, C21.2, C22.2, C23.2, C24.2, C25.2, C26.2, C27.2, C28.2, C29.2, C30.2, C31.2, C32.2, C33.2, C35.2, D1.2, D4.2, D5.2, D6.2, J1.2, J2.4, J3.2, J4.2, J5.2, J6.2, J7.2, J8.2, J9.1, J11.2, J12.3, JP1.2, J_PI.6, J_PI.9, J_PI.14, J_PI.20, J_PI.25, J_PI.30, J_PI.34, J_PI.39, Q2.1, Q5.1, Q7.1, Q9.1, Q10.1, R10.2, R12.2, R14.2, R21.2, R24.2, R29.2, U2.1, U3.2, U3.4, U4.2, U5.2, U8.2, U9.1, U9.2, U9.3, U9.4, U10.1, U10.3, U11.2, U12.2, U13.1
GNDISO: C34.2, C36.2, D8.2, D9.2, J10.3, R32.2, U12.6, U13.3
unnamed: BZ1.2, D7.2, Q10.3
unnamed: D8.1, J10.1, R30.1, R31.2, U12.7
unnamed: D9.1, J10.2, JP2.2, R32.1, U12.8
unnamed: J2.1, J_PI.32
unnamed: J2.2, J_PI.33
unnamed: J3.3, R17.1
unnamed: J4.3, R18.1
unnamed: F4.2, J11.1
unnamed: J12.1, R34.2
unnamed: JP1.1, R16.2, U9.7
unnamed: JP2.1, R30.2
unnamed: J_PI.27, U9.5
unnamed: J_PI.28, U9.6
unnamed: Q2.3, R8.2, U5.4
unnamed: Q2.2, R9.2, R10.1
unnamed: Q5.2, R13.2, R14.1
unnamed: Q6.2, Q7.3, R19.2
unnamed: Q7.2, R20.2, R21.1
unnamed: Q8.2, Q9.3, R22.2
unnamed: Q9.2, R23.2, R24.1
unnamed: Q10.2, R28.2, R29.1
unnamed: C3.2, R_SENSE2.2, U2.7
PH_VCC: C30.1, J3.1, Q6.1
VBAT: BT1.1, C13.1, F3.1, U4.3
VBAT_F: C14.1, F3.2, R8.1, R11.1, U5.1

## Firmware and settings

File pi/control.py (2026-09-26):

from __future__ import annotations

import argparse
import collections
import csv
import datetime as dt
import glob
import json
import math
import os
import queue
import random
import signal
import statistics
import sys
import threading
import time
from dataclasses import dataclass, field
from typing import (Callable, Deque, Dict, Iterable, List, Optional, Tuple)

from config import (CSV_DIR, DOSE_EC_DEADBAND, FAN_DUTY, DOSE_EC_TARGET, DOSE_FLOW_ML_PER_S,
                    DOSE_MAX_ML_PER_EVENT, DOSE_MAX_ML_PH_EVENT,
                    DOSE_MAX_SECONDS_PER_HOUR, DOSE_MIN_INTERVAL_S, DOSE_MIN_LEVEL_L,
                    DOSE_MIX_WAIT_S, DOSE_PH_DEADBAND, DOSE_PH_TARGET,
                    DOSE_VERIFY_FRACTION, DOSE_VERIFY_MAX_FRACTION, DOSING_CALIBRATED,
                    DOSING_ENABLED, EC_PER_ML, LIGHT_BRIGHTNESS, LIGHT_OFF_HOUR,
                    LIGHT_ON_HOUR, LIGHT_RAMP_MINUTES, MAX_FILL_DEPTH_MM,
                    MICRO_GRO_RATIO, MQTT_HOST, PH_CAL_V4, PH_CAL_V7, PH_PER_ML_DOWN,
                    PROBE_SETTLE_S, SAMPLE_INTERVAL_S, SENSOR_HEIGHT_MM, TDS_TEMP_COEFF,
                    TDS_TO_EC)

# ---------------------------------------------------------------------------
# hardware map, verified against hat.kicad_pcb -- this is not reasoned from
# memory, it's transcribed.
# ---------------------------------------------------------------------------

I2C_BUS = 1

INA226_ADDR = 0x40
PCA9685_ADDR = 0x41
SHT3X_ADDR = 0x44
ADS1115_PH_EC_ADDR = 0x48        # ph (A0), ec (A1), pump3 current (A2)
ADS1115_PUMP12_ADDR = 0x49       # pump1 current (A0), pump2 current (A2)
ADS1115_LED_ADDR = 0x4A          # led current (A0); A2 is genuinely floating, don't read it
SCD40_ADDR = 0x62                # standard address, not re-strapped
VEML7700_ADDR = 0x10             # standard address, not re-strapped
DS3231_ADDR = 0x68                # standard address, RTC not currently used by this loop

ADS_CH_PH, ADS_CH_EC, ADS_CH_PUMP3 = 0, 1, 2
ADS_CH_PUMP1, ADS_CH_PUMP2 = 0, 2
ADS_CH_LED = 0
ADS_FSR_PROBE_V = 4.096          # +-4.096V range, for the analog probe boards
ADS_FSR_SHUNT_V = 0.256          # +-0.256V range, for the low-side current shunts

PUMP_SHUNT_OHMS = {1: 0.1, 2: 0.1, 3: 0.1}     # R13/R16/R19
LED_SHUNT_OHMS = 0.01                          # R22
INA226_SHUNT_OHMS = 0.005                      # R_SHUNT, the 12V input

PIN_PH_POWER = 23           # /PH_EN
PIN_EC_POWER = 24           # /EC_EN
PIN_FLOW = 17               # /FLOW, off the CD40106 schmitt buffer
PIN_FAN_TACH = 27           # /FAN_TACH
PIN_HB_ALIVE = 18           # /HB_ALIVE -- the watchdog retrigger. see Watchdog below
PIN_ARM = 25                # /ARM -- the software's own deliberate arm/disarm

# the CD4538 monostable's timeout, measured off the real board: R1=470k, C2=10uF
# on MONO_RC/MONO_CEXT. CD4538 timeout ~= 0.7 * R * C -- verify on the bench, this
# is a datasheet-formula estimate, not a bench measurement.
WATCHDOG_TIMEOUT_S = 0.7 * 470_000 * 10e-6      # ~3.3s
WATCHDOG_TOGGLE_S = 1.0                          # retrigger well inside the timeout

JSN_SERIAL_PORT = "/dev/serial0"
JSN_BAUD = 9600

LEVEL_BLIND_ZONE_MM = 200.0
LEVEL_MAX_RANGE_MM = 6000.0
BUCKET_BORE_MM = 290.0
LEVEL_MIN_VALID_MM = SENSOR_HEIGHT_MM - MAX_FILL_DEPTH_MM
LEVEL_MAX_VALID_MM = SENSOR_HEIGHT_MM + 20.0

W1_DIR = "/sys/bus/w1/devices"
W1_PREFIX = "28-"

PH_CAL_7, PH_CAL_4 = 7.00, 4.00

RANGES = {
    "water/level":  (0.0, 20.0),
    "water/temp":   (0.0, 45.0),
    "water/ph":     (0.0, 14.0),
    "water/ec":     (0.0, 5000.0),
    "air/temp":     (-10.0, 60.0),
    "air/humidity": (0.0, 100.0),
    "air/co2":      (0.0, 10000.0),
    "air/light":    (0.0, 120000.0),
    "water/flow":   (0.0, 30.0),
    "pump/1/current": (0.0, 1.5),
    "pump/2/current": (0.0, 1.5),
    "pump/3/current": (0.0, 1.5),
    "lights/current": (0.0, 6.0),
    "fan/rpm":      (0.0, 10000.0),
    "board/armed":  (0.0, 1.0),
    "power/volts":  (9.0, 15.0),
    "power/current": (0.0, 10.0),
}

MQTT_PORT = 1883
MQTT_KEEPALIVE_S = 60
MQTT_CLIENT_ID = "hydro-control"
MQTT_TOPIC_PREFIX = "hydro"
MQTT_QOS = 1

CSV_HEADER = ["ts", "iso", "sensor", "value", "unit", "valid", "note"]


@dataclass(frozen=True)
class Reading:
    sensor: str
    value: float
    unit: str
    valid: bool
    ts: float = field(default_factory=time.time)
    note: str = ""

    @classmethod
    def bad(cls, sensor: str, unit: str, note: str, value: float = float("nan")) -> "Reading":
        return cls(sensor=sensor, value=value, unit=unit, valid=False, note=note)

    def __str__(self) -> str:
        if not self.valid:
            return f"{self.sensor:<14} FAIL  {self.note}"
        return f"{self.sensor:<14} {self.value:>9.2f} {self.unit}"


def checked(sensor: str, value: float, unit: str, note: str = "") -> Reading:
    lo, hi = RANGES[sensor]
    if value != value:
        return Reading.bad(sensor, unit, "nan")
    if not (lo <= value <= hi):
        return Reading(sensor=sensor, value=value, unit=unit, valid=False,
                       note=f"out of range {lo}..{hi}")
    return Reading(sensor=sensor, value=value, unit=unit, valid=True, note=note)


def crc8_sensirion(data: bytes) -> int:
    """Shared by every Sensirion part on this board: SHT31 and SCD40 both use it."""
    crc = 0xFF
    for byte in data:
        crc ^= byte
        for _ in range(8):
            crc = ((crc << 1) ^ 0x31) & 0xFF if crc & 0x80 else (crc << 1) & 0xFF
    return crc


class Sensor:
    name = "unnamed"

    def __init__(self, simulate: bool = False) -> None:
        self.simulate = simulate

    def read(self) -> List[Reading]:
        raise NotImplementedError

    def close(self) -> None:
        pass


class WaterTemp(Sensor):
    name = "water/temp"

    def __init__(self, simulate: bool = False) -> None:
        super().__init__(simulate)
        self._path: Optional[str] = None
        self._sim_c = 21.0
        if not simulate:
            self._path = self._find_probe()

    @staticmethod
    def _find_probe() -> Optional[str]:
        matches = sorted(glob.glob(os.path.join(W1_DIR, W1_PREFIX + "*", "w1_slave")))
        return matches[0] if matches else None

    def read(self) -> List[Reading]:
        if self.simulate:
            self._sim_c += random.uniform(-0.08, 0.08)
            self._sim_c = max(18.0, min(26.0, self._sim_c))
            return [checked(self.name, round(self._sim_c, 2), "C")]

        if self._path is None:
            self._path = self._find_probe()
            if self._path is None:
                return [Reading.bad(self.name, "C", "no 1-wire device found")]
        try:
            with open(self._path, "r") as fh:
                lines = fh.read().splitlines()
        except OSError as exc:
            self._path = None
            return [Reading.bad(self.name, "C", f"read failed: {exc}")]

        if len(lines) < 2 or not lines[0].strip().endswith("YES"):
            return [Reading.bad(self.name, "C", "1-wire crc failed")]
        marker = lines[1].find("t=")
        if marker < 0:
            return [Reading.bad(self.name, "C", "no t= field")]
        milli = int(lines[1][marker + 2:])
        if milli == 85000:
            return [Reading.bad(self.name, "C", "85C power-on default, conversion did not run", 85.0)]
        return [checked(self.name, milli / 1000.0, "C")]


CMD_MEASURE_HIGH_REPEATABILITY = (0x24, 0x00)
MEASURE_DELAY_S = 0.016


class AirSensor(Sensor):
    """SHT31 at 0x44. temp + humidity."""
    name = "air"

    def __init__(self, simulate: bool = False) -> None:
        super().__init__(simulate)
        self._bus = None
        self._sim_t, self._sim_rh = 22.0, 55.0
        if not simulate:
            import smbus2
            self._bus = smbus2.SMBus(I2C_BUS)

    def read(self) -> List[Reading]:
        if self.simulate:
            self._sim_t += random.uniform(-0.15, 0.15)
            self._sim_rh += random.uniform(-0.6, 0.6)
            self._sim_t = max(18.0, min(28.0, self._sim_t))
            self._sim_rh = max(35.0, min(85.0, self._sim_rh))
            return [checked("air/temp", round(self._sim_t, 2), "C"),
                    checked("air/humidity", round(self._sim_rh, 1), "%RH")]

        import smbus2
        try:
            self._bus.i2c_rdwr(smbus2.i2c_msg.write(SHT3X_ADDR, list(CMD_MEASURE_HIGH_REPEATABILITY)))
            time.sleep(MEASURE_DELAY_S)
            rx = smbus2.i2c_msg.read(SHT3X_ADDR, 6)
            self._bus.i2c_rdwr(rx)
            data = bytes(rx)
        except OSError as exc:
            note = f"i2c failed: {exc}"
            return [Reading.bad("air/temp", "C", note), Reading.bad("air/humidity", "%RH", note)]
        if len(data) != 6:
            note = f"short read, {len(data)} bytes"
            return [Reading.bad("air/temp", "C", note), Reading.bad("air/humidity", "%RH", note)]

        out: List[Reading] = []
        if crc8_sensirion(data[0:2]) != data[2]:
            out.append(Reading.bad("air/temp", "C", "crc failed"))
        else:
            ticks = (data[0] << 8) | data[1]
            out.append(checked("air/temp", round(-45.0 + 175.0 * ticks / 65535.0, 2), "C"))
        if crc8_sensirion(data[3:5]) != data[5]:
            out.append(Reading.bad("air/humidity", "%RH", "crc failed"))
        else:
            ticks = (data[3] << 8) | data[4]
            rh = 100.0 * ticks / 65535.0
            out.append(checked("air/humidity", round(max(0.0, min(100.0, rh)), 1), "%RH"))
        return out

    def close(self) -> None:
        if self._bus is not None:
            self._bus.close()


CMD_SCD40_START_PERIODIC = (0x21, 0xB1)
CMD_SCD40_READ_MEASUREMENT = (0xEC, 0x05)
CMD_SCD40_DATA_READY = (0xE4, 0xB8)


class Co2Sensor(Sensor):
    """SCD40 at 0x62. co2 + temp + humidity, but only co2 is used from here --
    air temp/humidity already come from the SHT31, which settles faster."""
    name = "air/co2"

    def __init__(self, simulate: bool = False) -> None:
        super().__init__(simulate)
        self._bus = None
        self._sim_co2 = 650.0
        if not simulate:
            import smbus2
            self._bus = smbus2.SMBus(I2C_BUS)
            try:
                self._bus.i2c_rdwr(smbus2.i2c_msg.write(SCD40_ADDR, list(CMD_SCD40_START_PERIODIC)))
            except OSError:
                pass  # first read() will report the failure

    def _write_read(self, cmd: Tuple[int, int], n: int, delay_s: float):
        import smbus2
        self._bus.i2c_rdwr(smbus2.i2c_msg.write(SCD40_ADDR, list(cmd)))
        time.sleep(delay_s)
        rx = smbus2.i2c_msg.read(SCD40_ADDR, n)
        self._bus.i2c_rdwr(rx)
        return bytes(rx)

    def read(self) -> List[Reading]:
        if self.simulate:
            self._sim_co2 += random.uniform(-15.0, 25.0)
            self._sim_co2 = max(420.0, min(1800.0, self._sim_co2))
            return [checked(self.name, round(self._sim_co2, 0), "ppm")]

        try:
            ready = self._write_read(CMD_SCD40_DATA_READY, 3, 0.001)
            if crc8_sensirion(ready[0:2]) != ready[2]:
                return [Reading.bad(self.name, "ppm", "data-ready crc failed")]
            if (((ready[0] << 8) | ready[1]) & 0x07FF) == 0:
                return [Reading.bad(self.name, "ppm", "not ready yet, 5s update cycle")]
            data = self._write_read(CMD_SCD40_READ_MEASUREMENT, 9, 0.001)
        except OSError as exc:
            return [Reading.bad(self.name, "ppm", f"i2c failed: {exc}")]

        if crc8_sensirion(data[0:2]) != data[2]:
            return [Reading.bad(self.name, "ppm", "crc failed")]
        co2 = (data[0] << 8) | data[1]
        return [checked(self.name, float(co2), "ppm")]

    def close(self) -> None:
        if self._bus is not None:
            self._bus.close()


VEML_ALS_CONF0 = 0x00
VEML_ALS = 0x04
VEML_LUX_PER_COUNT = 0.0576  # gain=1x, integration=100ms, per Vishay's app note table


class LightSensor(Sensor):
    """VEML7700 at 0x10. confirms the LED strip/photoperiod are doing something --
    not a control input, the photoperiod schedule is timer-based (see Lights)."""
    name = "air/light"

    def __init__(self, simulate: bool = False) -> None:
        super().__init__(simulate)
        self._bus = None
        self._sim_lux = 8000.0
        if not simulate:
            import smbus2
            self._bus = smbus2.SMBus(I2C_BUS)
            try:
                # gain=1x, IT=100ms, not shutdown. see VEML_LUX_PER_COUNT's comment.
                self._bus.write_word_data(VEML7700_ADDR, VEML_ALS_CONF0, 0x0000)
            except OSError:
                pass

    def read(self) -> List[Reading]:
        if self.simulate:
            self._sim_lux += random.uniform(-200.0, 200.0)
            self._sim_lux = max(0.0, min(20000.0, self._sim_lux))
            return [checked(self.name, round(self._sim_lux, 0), "lux")]
        try:
            raw = self._bus.read_word_data(VEML7700_ADDR, VEML_ALS)
        except OSError as exc:
            return [Reading.bad(self.name, "lux", f"i2c failed: {exc}")]
        return [checked(self.name, round(raw * VEML_LUX_PER_COUNT, 0), "lux")]

    def close(self) -> None:
        if self._bus is not None:
            self._bus.close()


BORE_AREA_MM2 = math.pi * (BUCKET_BORE_MM / 2.0) ** 2


class TankLevel(Sensor):
    """JSN-SR04T, wired directly in its own native UART mode (9600 8N1): a 4-byte
    frame, 0xFF header + distance high byte + distance low byte + checksum, sent
    continuously on its own. No more relaying through a pumps board -- this reads
    the sensor's wire protocol directly."""
    name = "water/level"

    def __init__(self, simulate: bool = False) -> None:
        super().__init__(simulate)
        self._ser = None
        self._sim_distance = SENSOR_HEIGHT_MM - 80.0
        if not simulate:
            import serial
            self._ser = serial.Serial(JSN_SERIAL_PORT, JSN_BAUD, timeout=0.3)

    @staticmethod
    def depth_to_litres(depth_mm: float) -> float:
        return depth_mm * BORE_AREA_MM2 / 1_000_000.0

    def _read_distance_mm(self) -> Optional[float]:
        # hunt for the 0xFF header rather than assuming byte alignment -- the
        # sensor free-runs, so a stale partial frame can be sitting in the buffer
        for _ in range(4):
            header = self._ser.read(1)
            if not header:
                return None
            if header[0] != 0xFF:
                continue
            rest = self._ser.read(3)
            if len(rest) != 3:
                return None
            data_h, data_l, checksum = rest
            if (0xFF + data_h + data_l) & 0xFF != checksum:
                continue
            return float((data_h << 8) | data_l)
        return None

    def read(self) -> List[Reading]:
        if self.simulate:
            self._sim_distance += random.uniform(-1.0, 1.0)
            self._sim_distance = max(LEVEL_MIN_VALID_MM, min(LEVEL_MAX_VALID_MM, self._sim_distance))
            distance = self._sim_distance
        else:
            try:
                distance = self._read_distance_mm()
            except OSError as exc:
                return [Reading.bad(self.name, "L", f"serial failed: {exc}")]
            if distance is None:
                return [Reading.bad(self.name, "L", "no valid frame from the sensor")]

        if distance < LEVEL_BLIND_ZONE_MM:
            return [Reading.bad(self.name, "L",
                                f"{distance:.0f}mm inside the {LEVEL_BLIND_ZONE_MM:.0f}mm blind zone")]
        if distance > LEVEL_MAX_RANGE_MM:
            return [Reading.bad(self.name, "L", f"{distance:.0f}mm beyond sensor range")]
        if not (LEVEL_MIN_VALID_MM <= distance <= LEVEL_MAX_VALID_MM):
            return [Reading.bad(self.name, "L", f"{distance:.0f}mm outside tank window "
                                f"{LEVEL_MIN_VALID_MM:.0f}..{LEVEL_MAX_VALID_MM:.0f}")]
        depth = SENSOR_HEIGHT_MM - distance
        return [checked(self.name, round(self.depth_to_litres(depth), 2), "L",
                        note=f"distance {distance:.0f}mm")]

    def close(self) -> None:
        if self._ser is not None:
            self._ser.close()


class PulseCounter:
    """A GPIO edge counter for anything that outputs pulses: the flow sensor and
    the fan tachometer are both this, just with different pulses-per-unit."""

    def __init__(self, pin: int, simulate: bool = False, sim_hz: float = 0.0) -> None:
        self.simulate = simulate
        self._count = 0
        self._lock = threading.Lock()
        self._dev = None
        self._sim_hz = sim_hz
        if not simulate:
            from gpiozero import DigitalInputDevice
            self._dev = DigitalInputDevice(pin, pull_up=False)
            self._dev.when_activated = self._tick

    def _tick(self) -> None:
        with self._lock:
            self._count += 1

    def hz_since_last_call(self) -> float:
        """Call this on a roughly-known interval (the sweep interval); it hands
        back edges-per-second since the last call and resets the counter."""
        if self.simulate:
            return self._sim_hz
        with self._lock:
            n, self._count = self._count, 0
        return n  # caller divides by however many seconds actually elapsed

    def close(self) -> None:
        if self._dev is not None:
            self._dev.close()


class FlowAndFan(Sensor):
    """Flow sensor (BCM17) and fan tach (BCM27). The flow sensor module itself
    isn't sourced yet, so this will report 'no pulses' until one is plugged
    in. That's expected, not a fault."""
    name = "flow_fan"
    FLOW_HZ_PER_LPM = 7.5  # carried over from the old design's flow sensor spec;
                           # re-verify once an actual sensor is sourced and dated

    def __init__(self, simulate: bool = False, interval_s: float = SAMPLE_INTERVAL_S) -> None:
        super().__init__(simulate)
        self.interval_s = interval_s
        self._last_ts = time.time()
        self.flow = PulseCounter(PIN_FLOW, simulate, sim_hz=0.0)
        self.fan = PulseCounter(PIN_FAN_TACH, simulate, sim_hz=(FAN_DUTY * 2400.0 / 60.0 * 2))

    def read(self) -> List[Reading]:
        now = time.time()
        elapsed = max(0.5, now - self._last_ts)
        self._last_ts = now
        flow_hz = self.flow.hz_since_last_call() / elapsed
        fan_hz = self.fan.hz_since_last_call() / elapsed
        out = [checked("water/flow", round(flow_hz / self.FLOW_HZ_PER_LPM, 2), "L/min",
                       note=f"{flow_hz:.1f} Hz" if flow_hz else "no pulses -- sensor not connected yet")]
        # most PC-style fan tachs pulse twice per revolution
        out.append(checked("fan/rpm", round(fan_hz / 2.0 * 60.0, 0), "rpm"))
        return out

    def close(self) -> None:
        self.flow.close()
        self.fan.close()


class Supply(Sensor):
    """The HAT's own 12V input: the INA226 at 0x40. no mains-sense and no
    battery in this design -- both were cut with the UPS."""
    name = "power"

    def __init__(self, simulate: bool = False) -> None:
        super().__init__(simulate)
        self._bus = None
        if not simulate:
            import smbus2
            self._bus = smbus2.SMBus(I2C_BUS)

    def read(self) -> List[Reading]:
        if self.simulate:
            return [checked("power/current", 1.35, "A"), checked("power/volts", 12.05, "V")]
        out: List[Reading] = []
        try:
            raw = self._bus.read_word_data(INA226_ADDR, 0x02)
            bus_v = ((raw & 0xFF) << 8 | raw >> 8) * 1.25e-3
            raw = self._bus.read_word_data(INA226_ADDR, 0x01)
            sv = (raw & 0xFF) << 8 | raw >> 8
            sv = sv - 65536 if sv > 32767 else sv
            out.append(checked("power/volts", round(bus_v, 2), "V"))
            out.append(checked("power/current", round(sv * 2.5e-6 / INA226_SHUNT_OHMS, 3), "A"))
        except OSError as exc:
            out.append(Reading.bad("power/volts", "V", f"ina226: {exc}"))
        return out

    def close(self) -> None:
        if self._bus is not None:
            self._bus.close()


REG_CONVERSION, REG_CONFIG = 0x00, 0x01
_MUX = {0: 0b100, 1: 0b101, 2: 0b110, 3: 0b111}   # single-ended vs GND, per channel
_PGA_4V096, _PGA_0V256, _DR_128SPS = 0b001, 0b101, 0b100


def _config_word(channel: int, pga: int) -> int:
    return 0x8000 | (_MUX[channel] << 12) | (pga << 9) | (1 << 8) | (_DR_128SPS << 5) | 0x03


def _read_ads1115_volts(bus, address: int, channel: int, pga: int, fsr: float) -> Optional[float]:
    cfg = _config_word(channel, pga)
    try:
        bus.write_i2c_block_data(address, REG_CONFIG, [(cfg >> 8) & 0xFF, cfg & 0xFF])
        time.sleep(1.0 / 128 + 0.002)
        raw = bus.read_i2c_block_data(address, REG_CONVERSION, 2)
    except OSError:
        return None
    counts = (raw[0] << 8) | raw[1]
    if counts > 0x7FFF:
        counts -= 0x10000
    return counts * fsr / 32768.0


def ph_from_volts(v: float) -> float:
    slope = (PH_CAL_7 - PH_CAL_4) / (PH_CAL_V7 - PH_CAL_V4)
    return PH_CAL_7 + (v - PH_CAL_V7) * slope


def tds_from_volts(v: float, water_temp_c: float) -> float:
    comp = v / (1.0 + TDS_TEMP_COEFF * (water_temp_c - 25.0))
    return (133.42 * comp ** 3 - 255.86 * comp ** 2 + 857.39 * comp) * 0.5
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

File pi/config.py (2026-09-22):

"""The numbers you might have to change.

Everything fixed by the hat, the wiring or the bucket is at the top of control.py
and should not need touching. Everything here is a measurement, a target or a
preference.

Lines marked MEASURE are guesses until they are measured on the bench, and the
dosing ones are refused on hardware until DOSING_CALIBRATED is flipped.
"""

from __future__ import annotations

# ---------------------------------------------------------------- where things are

MQTT_HOST = "localhost"     # the broker. it runs on this pi
SAMPLE_INTERVAL_S = 60.0    # seconds between sweeps
CSV_DIR = "data"            # daily csv files, relative to pi/

# ---------------------------------------------------------------- tank

# Both in mm from the bucket floor. The sensor face is the level sensor's transducer
# in the cap's pod, which the cad puts 6 below the bucket rim of a 368 tall bucket.
# Measure it with the ring and cap on: a tape from the floor to the pod opening.
SENSOR_HEIGHT_MM = 362.0    # MEASURE
MAX_FILL_DEPTH_MM = 160.0   # the fill line, about 10.6 L. leaves 202 mm of air above
                            # a full tank, just past the sensor's 200 mm blind zone

# ---------------------------------------------------------------- probe calibration

# pH, two point. Probe in the 7.00 buffer, note the volts. Then the 4.00 buffer.
PH_CAL_V7 = 2.500           # MEASURE, volts in the pH 7.00 buffer
PH_CAL_V4 = 3.040           # MEASURE, volts in the pH 4.00 buffer

# TDS to EC. The Gravity board is dc excitation, so it needs the water temp.
TDS_TEMP_COEFF = 0.02       # per degree C, referenced to 25 C
TDS_TO_EC = 2.0             # ec (uS/cm) = tds (ppm) * 2
PROBE_SETTLE_S = 2.0        # wait after powering a probe before sampling. MEASURE

# ---------------------------------------------------------------- lights

LIGHT_ON_HOUR = 6.0         # 06:00
LIGHT_OFF_HOUR = 22.0       # 22:00, a 16 hour photoperiod. may cross midnight
LIGHT_BRIGHTNESS = 1.0      # 1.0 is the full 54 W. pwm only dims
LIGHT_RAMP_MINUTES = 10.0   # fade in and out. 0 snaps
FAN_DUTY = 0.5              # the hat fan, PCA9685 ch4, 0..1

# ---------------------------------------------------------------- dosing

DOSING_ENABLED = True
DOSING_CALIBRATED = False   # flip to True only after the three MEASURE blocks below

# 1. run each pump 60 s into a measuring cylinder, divide by 60
DOSE_FLOW_ML_PER_S = {
    "micro":   1.5,         # MEASURE
    "gro":     1.5,         # MEASURE
    "ph_down": 1.5,         # MEASURE
}

# 2. dose 5 mL, wait for the tank to mix, read the ec delta, divide by 5
EC_PER_ML = {
    "micro": 22.0,          # MEASURE, uS/cm per mL in a full tank
    "gro":   18.0,          # MEASURE
}

# 3. same for ph. non-linear because the solution buffers, so measure near target
PH_PER_ML_DOWN = 0.06       # MEASURE, ph units per mL

# targets for leafy greens
DOSE_EC_TARGET = 1200.0     # uS/cm
DOSE_EC_DEADBAND = 100.0    # do nothing inside target +/- this
DOSE_PH_TARGET = 5.8
DOSE_PH_DEADBAND = 0.3
MICRO_GRO_RATIO = 1.0       # gro per micro. micro always goes in first

# safety. these stop a stuck pump emptying a bottle
DOSE_MAX_ML_PER_EVENT = 5.0         # nutrients
DOSE_MAX_ML_PH_EVENT = 1.0          # ph down, far stronger per mL
DOSE_MAX_SECONDS_PER_HOUR = 30.0    # the hard cap from the spec
DOSE_MIN_INTERVAL_S = 600.0         # 10 min between doses
DOSE_MIX_WAIT_S = 300.0             # 5 min for the tank to mix before checking
DOSE_MIN_LEVEL_L = 5.0              # never dose into a nearly empty tank
DOSE_VERIFY_FRACTION = 0.4          # the reading must move at least this much of
                                    # what was expected, or the dose did not land
DOSE_VERIFY_MAX_FRACTION = 4.0      # and no more than this, or the pump did not stop

# ---------------------------------------------------------------- healthy bands

# Where each reading should sit. The dashboard colours by these and the alerts
# fire on them. Outside these is "the plants are unhappy"; control.py has the
# much wider "the sensor is broken" limits.
BANDS = {
    "water/level":  (6.0,  11.0),     # litres. full is the fill line
    "water/ph":     (5.5,   6.1),
    "water/ec":     (1100, 1300),     # uS/cm
    "water/temp":   (18.0, 24.0),     # C
    "air/temp":     (18.0, 28.0),
    "air/humidity": (40.0, 70.0),     # %RH
    "air/co2":      (400.0, 1500.0),  # ppm. no enrichment -- flags a stuffy room, not a plant target
}

# ---------------------------------------------------------------- alerts

# Phone notifications go through ntfy. Install the app, subscribe to a topic name
# nobody would guess, and put it here. Blank means log to the terminal only.
ALERT_NTFY_TOPIC = ""
ALERT_NTFY_SERVER = "https://ntfy.sh"
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

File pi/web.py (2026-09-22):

from __future__ import annotations

import argparse
import collections
import json
import os
import queue
import random
import sys
import tempfile
import threading
import time
import urllib.error
import urllib.request
from typing import Deque, Dict, List, Optional, Tuple

from flask import Flask, jsonify, request, send_file

from config import (ALERT_HEARTBEAT_S, ALERT_LEVEL_LOW_L, ALERT_LEVEL_RISE_L,
                    ALERT_LEVEL_RISE_WINDOW_S, ALERT_NTFY_SERVER, ALERT_NTFY_TOPIC,
                    ALERT_OUT_OF_BAND_S, ALERT_REPEAT_S, ALERT_SENSOR_FAIL_S, BANDS,
                    MAX_FILL_DEPTH_MM, MQTT_HOST)
from control import MQTT_PORT, MQTT_TOPIC_PREFIX, TankLevel
from store import DB_PATH, Store

HERE = os.path.dirname(os.path.abspath(__file__))
PAGE = os.path.join(HERE, "dashboard.html")
TOWER = os.path.join(HERE, "..", "images", "tower-assembly.png")

app = Flask(__name__)
app.config["db_path"] = DB_PATH

SENSORS = [
    ("water/level",  "water level", "L",     *BANDS["water/level"]),
    ("water/ph",     "pH",          "pH",    *BANDS["water/ph"]),
    ("water/ec",     "EC",          "uS/cm", *BANDS["water/ec"]),
    ("water/temp",   "water temp",  "C",     *BANDS["water/temp"]),
    ("air/temp",     "air temp",    "C",     *BANDS["air/temp"]),
    ("air/humidity", "humidity",    "%RH",   *BANDS["air/humidity"]),
    ("air/co2",      "CO2",         "ppm",   *BANDS["air/co2"]),
]
LABELS = {k: (label, unit, lo, hi) for k, label, unit, lo, hi in SENSORS}
TANK_FULL_L = round(TankLevel.depth_to_litres(MAX_FILL_DEPTH_MM), 1)
BOTTLE_ML = 1000.0
CHANNEL_LABEL = {"micro": "FloraMicro", "gro": "FloraGro", "ph_down": "pH Down"}

SENSOR_PREFIX = f"{MQTT_TOPIC_PREFIX}/sensor/"
STATE_PREFIX = f"{MQTT_TOPIC_PREFIX}/state/"
TOPIC_ALERTS = f"{MQTT_TOPIC_PREFIX}/state/alerts"


def store() -> Store:
    return Store(app.config["db_path"])


def _mqtt_client(client_id: str):
    try:
        import paho.mqtt.client as mqtt
    except ImportError:
        return None
    try:
        return mqtt.Client(mqtt.CallbackAPIVersion.VERSION2, client_id=client_id)
    except AttributeError:
        return mqtt.Client(client_id=client_id)


class Commands:
    def __init__(self, host: str = MQTT_HOST, port: int = MQTT_PORT) -> None:
        self.client = _mqtt_client("hydro-web")
        if self.client is None:
            return
        try:
            self.client.connect_async(host, port, 60)
            self.client.loop_start()
        except Exception:
            self.client = None

    def send(self, name: str, body: dict) -> bool:
        if self.client is None:
            return False
        try:
            return self.client.publish(f"{MQTT_TOPIC_PREFIX}/cmd/{name}", json.dumps(body), qos=1).rc == 0
        except Exception:
            return False


commands: Optional[Commands] = None


def state_of(s: Store, topic: str) -> dict:
    row = s.latest_event(f"{STATE_PREFIX}{topic}")
    if not row:
        return {}
    try:
        return json.loads(row["payload"])
    except (json.JSONDecodeError, ValueError):
        return {}


def band_status(sensor: str, value: Optional[float], valid: bool) -> str:
    if not valid or value is None:
        return "bad"
    _, _, lo, hi = LABELS.get(sensor, ("", "", None, None))
    if lo is None:
        return "ok"
    return "ok" if lo <= value <= hi else "warn"


def snapshot() -> dict:
    s = store()
    try:
        latest = {r["sensor"]: r for r in s.latest()}
        now = int(time.time())
        since = now - 24 * 3600
        out = []
        for key, label, unit, lo, hi in SENSORS:
            r = latest.get(key)
            value = r["value"] if r else None
            valid = bool(r["valid"]) if r else False
            pts = [round(p["v"], 3) for p in s.series(key, since)] if r else []
            out.append({"sensor": key, "label": label, "unit": unit, "value": value,
                        "valid": valid, "age": now - r["ts"] if r else None,
                        "note": r["note"] if r else "", "lo": lo, "hi": hi,
                        "status": band_status(key, value, valid), "series": pts,
                        "delta": round(pts[-1] - pts[0], 2) if len(pts) > 1 else None})
        online = state_of(s, "online")
        heartbeat = online.get("timestamp")
        alerts = state_of(s, "alerts")
        return {
            "sensors": out,
            "lights": state_of(s, "lights"),
            "dosing": state_of(s, "dosing"),
            "alerts": [a for a in alerts.get("active", []) if isinstance(a, dict)],
            "tank_full_l": TANK_FULL_L,
            "online": bool(online.get("online")) and (heartbeat is not None and now - heartbeat < 300),
            "last_seen": heartbeat,
            "now": now,
        }
    finally:
        s.close()
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

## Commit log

2026-08-25 adding the parameters and cad readme
2026-08-25 adding the socket test plate step file
    [socket_test_plate_50.6mm_v1.step]
2026-08-25 switching to a pi only build
2026-08-25 adding the wiring diagram to the readme
2026-08-25 adding the bom
    [BOM.csv]
2026-08-26 switching the module joints to tie rods
    [BOM.csv]
2026-08-26 reordering the rod parameters so they resolve
2026-08-26 grouping the bom into own, self funded, and need
    [BOM.csv]
2026-08-26 splitting the bom into three tables
    [BOM.csv]
2026-08-26 back to one table with a blank row between the groups
    [BOM.csv]
2026-08-26 updated BOM (edited self-funded and owned categories)
    [BOM.csv]
2026-08-26 adding all the links
    [BOM.csv]
2026-08-26 filling in the real part links and prices
    [BOM.csv]
2026-08-26 swapping the led strip and adding the sensor riser
    [BOM.csv]
2026-09-06 verifying every bom link and swapping the tie rods and led channel
    opened all 27 product links against live pages. 15 descriptions named a brand,
    model or pack size the listing does not actually have.
    - tie rods m5 -> #10-24. metric 1m all-thread is a us specialty import at
    15.63 each, #10-24 is 2.98 and its 4.83mm major dia drops into the existing
    6.5 hole with more slop than m5 had, so no cad change
    - led channel vst -> muzata, 39.99 -> 19.99. the vst was also only rated to
    10mm strip width against a 12mm 5630
    - added 7 lines missing entirely: peristaltic tubing, 22 and 16awg wire, ph
    probe storage solution, pvc tee, elbow, and solvent cement
    - drip holes 8 x d8 -> 4 x d10 one und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
    [BOM.csv]
2026-09-06 folding the bom down to 8 columns and dropping the gfci adapter
    - merged "why i need it" into the description and cut the notes column.
    description text is 40 percent shorter, the funding reason kept
    - removed the gfci adapter, the outlet already has one. every doc already
    said "gfci outlet" so nothing else changed
    - renamed the sht41 line to sht31, which is the part actually linked
    481.67, 118.33 under the grant.
    [BOM.csv]
2026-09-06 swapping in a ul listed psu
    the old part was ly liu yun b07tjp91qh, ip67 but ce/rohs only, so no us
    safety listing on the one mains part in the build, next to an open tank.
    fsjee ysd-12100-qtl, 34.99 against 34.88. verified two ways: the listing
    says ul listed in the title, a bullet and the spec table, and ul's own
    database has file e498189 to shenzhen yanshuoda with ysd-12100-qtl in the
    model list. wet location rated and fully potted with a moulded 3-prong
    cord, so no enclosure and no earth bond to get wrong.
    mean well lrs-100-12 was rejected: 15 of 16 listings state no nrtl claim
    at all, and it is an uncovered live 120v barrier strip that needs about
    63 dollars of enclosure and cord to b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
    [BOM.csv]
2026-09-08 cleaning up the repo and adding the step files for the grow module and root grate
    [socket_test_plate_50.6mm_v1.step]
2026-09-09 adding the spreader, tower lid and cap, and cutting the joint recess thru the rod bosses on the module
    [50.6 Test Socket.step, Grow Module.step, Lid Cap.step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]
2026-09-10 adding the drain base, and cutting rod length down to 870 cuz 890 bottoms out in the nut pockets
    [Drain Base.step]
2026-09-10 adding the tank lid plate with the sensor pod, and dropping the fill line to 165 so the level sensor clears its blind zone
    [Tank Lid Plate.step]
2026-09-10 fixing the floating pipe collar on the tank lid plate and adding the tower assembly
    [Tank Lid Plate.step]
2026-09-10 spec: drop the sensor riser and the bulkhead, neither of them exists
2026-09-10 dropping the bulkhead fitting, theres nothing for it to seal
    [BOM.csv]
2026-09-12 tank plate is now a cap that screws into a printed ring, the drain base twist locks onto it, gamma seal off the bom
    [BOM.csv, Drain Base.step, Tank Lid Plate.step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]
2026-09-12 shorter cad readme, images moved to their own folder
2026-09-12 Clean up assembly section in README
    Removed detailed assembly instructions for various parts.
2026-09-12 dropping the fill line to 160 cuz the sensor face sits 6 below the rim now the plate is a cap
2026-09-12 adding the control loop, sensors lights dosing csv and mqtt, and taking pi out of the gitignore
2026-09-12 plain html dashboard, one page with tables, and the onshape assembly render as the tower picture
2026-09-17 tracking the pcb folder: the kicad projects for the hat and the pumps board, and their gerbers
    [BOM.csv, hat.kicad_pcb, hat.kicad_sch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]
2026-09-17 pumps board firmware for the pico: command frames in on the heartbeat line, telemetry out on the fault line
2026-09-17 the pi drives the pumps board over the two wire link, lights and pumps and tank level go through it
2026-09-19 ignoring the pico firmware build directory
2026-09-19 compiled the pico firmware
2026-09-21 i redid everything for one board, one pi 5, and cut some features
    [BOM.csv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]
2026-09-21 price the BOM down: AliExpress swaps, cut unused parts, waste-reduced kits
    [BOM.csv]
2026-09-21 fix ADS1115 count: schematic has 3 (0x48/0x49/0x4A), not 2 -- BOM description was stale
    [BOM.csv]
2026-09-21 pi: architecture spec for the single-board Pi 5 + HAT design, verified pin map from hat.kicad_pcb
2026-09-21 pi: drop link.py, firmware/ and pigpio -- the pumps board is gone
2026-09-21 pi: track the tests -- they were gitignored and only existed locally
2026-09-21 pi: scrub the last pumps-board references from web.py, README and tests
2026-09-22 pi: rewrite control.py for the single-board hat -- direct I2C/GPIO, no more link.py
    Replaces every hardware-access path that depended on the deleted pumps-board link:
    - 3x ADS1115 (0x48/0x49/0x4A) for ph/ec and all 4 current-sense shunts, single-ended
    reads against GND per the verified schematic map, not the differential wiring an
    earlier draft of ARCHITECTURE.md assumed
    - PCA9685 driven directly over smbus2 (no vendor library), all 7 used channels
    - JSN-SR04T read directly over /dev/serial0 in its native framed UART protocol
    - SCD40 (co2) and VEML7700 (light) added -- both were on the I2C bus and unread
    - flow sensor + fan tach as a shared PulseCounter off BCM17/BCM27
    - a Watchdog class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
    [control.py]
2026-09-22 web: give co2 a dashboard tile and alert on a disarmed watchdog
    air/co2 is a real plant-health signal, banded in config.py like the other
    six headline sensors and wired into the dashboard trend cards. board/armed
    now feeds a hand-written "watchdog disarmed" alert alongside the existing
    offline/dosing-fault conditions -- pumps and lights go dead when it trips,
    so it belongs with the other urgent alerts, not the generic band checks.
    air/light and fan/rpm stay stored-but-not-headline, same treatment the old
    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
2026-09-26 readme: gallery, PCB badge, corrected water mechanism, BOM table; gitignore kicad editor scratch files
2026-09-26 cad: export the hat as a standalone STEP; readme: 3D PCB render, fix kicanvas badge path
    [HAT.step]
2026-09-26 cad: add the full tower assembly as one STEP file
    [Tower Assembly.step]
2026-09-26 Update README.md for clarity and conciseness
    Removed outdated descriptions and clarified assembly instructions.
2026-09-26 pcb: shrunk board by about 47.5%
    [hat.kicad_pcb]
2026-09-26 new pcb image
2026-09-26 Change PCB image alt text to 'pcb'
    Updated image alt text for PCB in README.
2026-09-26 Revise README to clarify archived PCB design
    Updated the README to reflect the archived status of the old PCB design for the vertical garden.
2026-09-26 update pcb size in README, remove stale pi docs and tests
    board is 217x226mm now (was 330x283mm). removed parameters.md,
    pi/ARCHITECTURE.md, pi/README.md, and pi/tests -- no longer needed.
2026-09-26 move pcb badge to top, strip dangling ARCHITECTURE.md refs
    badge now sits with the onshape/kicanvas links up top instead of
    buried under the photos. control.py comments no longer point at
    ARCHITECTURE.md, which was removed.
    [control.py]
2026-09-26 Simplify BOM descriptions and fix PCB fab price
    [BOM.csv]
2026-09-26 Simplify twoboard BOM and add Onshape badge to hero
    [BOM.csv]
